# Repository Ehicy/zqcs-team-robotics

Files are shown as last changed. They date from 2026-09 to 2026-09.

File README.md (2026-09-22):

# CRTC2026 双车机器人项目

上层车推送黄块，下层车使用翻转臂和夹爪收集、接料。项目背景与当前决策见 [PROJECT.md](PROJECT.md)。

## 最新机械设计

### 翻转臂与料仓 v3（2026-09-21）

根据实物舵机照片补充MG995、SG90外形和安装托架，提供夹取、抬升、投料三个姿态。

- [完整CAD文件包](output/mechanics/flip-arm-sw-v3/FlipArm_V3_photo_fit.zip)
- [投料姿态STEP](output/mechanics/flip-arm-sw-v3/FlipArm_V3_deposit.STEP)
- [SolidWorks装配](output/mechanics/flip-arm-sw-v3/FlipArm_V3_deposit.SLDASM)
- [尺寸、照片依据和修改说明](output/mechanics/flip-arm-sw-v3/README.md)
- [舵机实物参考照片](pic/)

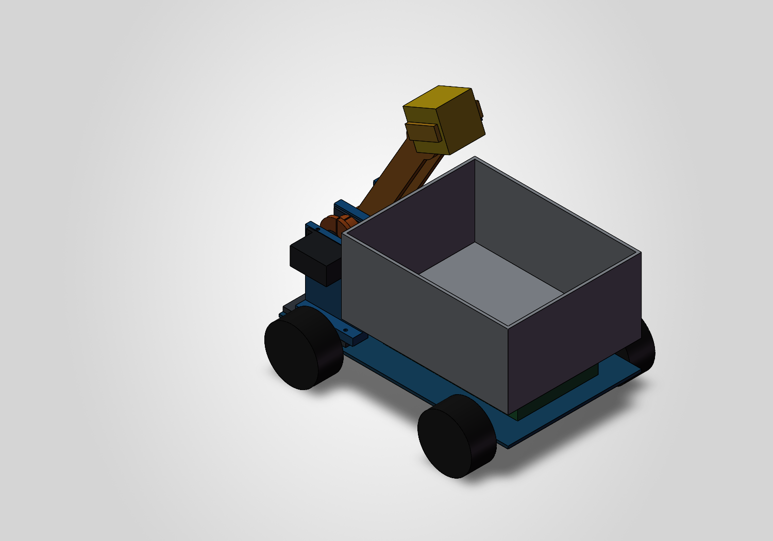
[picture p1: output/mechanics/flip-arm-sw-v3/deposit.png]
v3装配预览


原生文件使用SolidWorks 2026；下载ZIP并完整解压后打开SLDASM，保留同目录零件依赖。其他CAD软件可尝试STEP。当前为装配草案，SG90至夹指的传动、托架至腕部的连接尚未完成，不能把参考舵机和轴承模型作为打印零件。

### 桥梁试验模型

- [带两端高台的完整文件包](output/mechanics/bridge-platforms-v2/Bridge_with_platforms_TEST.zip)
- [带高台STEP](output/mechanics/bridge-platforms-v2/Bridge_with_platforms_TEST.STEP)
- [桥梁模型说明](output/mechanics/bridge-platforms-v2/README.md)
- [单段桥板模型与说明](output/mechanics/bridge-test-v1/README.md)

模型用于150mm桥面通行试验；桥曲线、厚度及净空解释包含假设，不能视为官方场地精确复刻。

## 文件位置

| 目录/文件 | 内容 |
|---|---|
| `output/mechanics/flip-arm-sw-v3/` | 当前舵机照片适配版本 |
| `output/mechanics/flip-arm-sw-v1/`、`flip-arm-sw-v2/` | 历史机械臂版本与生成脚本 |
| `output/mechanics/bridge-platforms-v2/` | 带高台的桥梁装配 |
| `output/power/`、`output/signals/` | 供电与信号方案 |
| `pic/` | 实物尺寸参考照片 |
| `PROJECT.md` | 项目背景、设计决策、工作流程和验收边界 |

CAD目录中的`build.ps1`、`build.cs`为本机SolidWorks API生成脚本；模板和API路径按本机安装配置。重新生成会覆盖相应输出，应先备份并阅读该目录说明。`backups/`、`tmp/`以及BMP预览中间文件作为本地工作资料，新文件不纳入Git。

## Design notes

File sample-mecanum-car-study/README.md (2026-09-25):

# 麦克纳姆轮小车：电控新手学习修订版

基于 Serialist/sample-mecanum-car 的 `1fa85bbdcd6c62f33f871284b642959cea975805`，2026-09-15 检查和修改。

**2026-09-24：已适配两块 DRV8833 控制四个电机，TIM2/TIM3 双输入 PWM，默认 20 kHz。实际轮位、方向、电流和遥控失联行为仍需实测。**

先打开：
- [检查与修改记录](docs/REVIEW.zh-CN.md)：发现的问题、修复方式、测试范围与剩余限制。
- [电控 B 阅读指引](docs/LEARNING.zh-CN.md)：按四个源码文件逐步学习。
- [测试结果](docs/TEST_RESULTS.txt)。
- Keil 工程：`user/rmcic.uvprojx`，保留标准库与 ARM Compiler 5 配置。

本版主循环在上电/通信异常后等待摇杆回中且按键全部松开，随后才接受控制；无效包清零电机输出。接收器若持续返回格式正确的旧帧，程序仍不能确认无线失联，须实测。

电机驱动 TODO 已完成；`TODO_GRIPPER` 仍是夹爪动作占位。当前接线、编译烧录与验收见 [DRV8833 说明](docs/DRV8833.zh-CN.md)。主机测试运行 `python tests/run_tests.py`，需要 Python 3 和 GCC；Windows 缺少 UBSan 时先设置 `$env:SANITIZE='0'`。

新增独立 GNU 构建入口：`python build_firmware.py --toolchain <Arm GNU bin目录>`，输出 `build/crtc-motor.hex`。原 Keil 工程保留。

以下保留原项目说明，材料清单和引脚描述属于上游硬件：

---

# STM32的简单麦克纳姆轮小车

## 简介

这个是一个由 STM32 最小单片机实现的简单麦克纳姆轮小车，包括了简单的 PWM 波输出和麦轮解算操作。

### 材料

- STM32F103C8T6 单片机最小系统板
- L298N 电机驱动模块
- LM2596 降压模块
- GBJ37-520 电机
- PS2 手柄及其接收器
- 小车底盘
- Keil 5

## 目录

```
├── hardware/           # 代码目录
│   ├── Inc/            # 头文件
│   └── Src/            # 程序文件
│       ├── main.c      # 主程序
│       ├── motor.c     # 底盘控制
│       ├── ps2.c       # PS2 数据接受程序
│       ├── pwm.c       # PWM
│       ├── delay.c     # 软件延时函数
│       └── sys.c       # 系统配置相关
├── lib/                # 硬件库
├── user/               # Keil 5 工程文件
└── README.md           # 项目说明文件
```

##  引脚定义

使用了PORTA PORTB

- motor PWM引脚定义

1 -> PA6  
2 -> PA7  
3 -> PB0  
4 -> PB1  

- motor逻辑引脚定义

1 -> PA8 PA9  
2 -> PA10 PA11  
3 -> PA5 PA4  
4 -> PA3 PA2  

- ps2数据引脚定义

DATA -> PB12  
CMD -> PB13  
CS -> PB14  
CLK -> PB15

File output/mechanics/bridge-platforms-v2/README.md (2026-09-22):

# 带两端高台的桥梁试验装配 v2

用户要求在原试验桥上增加高台。原v1文件保留。本装配由两座300×300×300mm高台、两段300×150mm试验桥板组成；整体长1200mm、宽300mm、最高315mm。

桥板两端上表面与高台上表面均为Y=300mm，单段中部315mm。桥板沿用v1圆弧起拱15mm、竖直厚度10mm的假设，整体上移175mm。两段相接处无高度落差，但曲线切线不连续；这种两段起拱形状没有得到官方CAD确认。

规则第15页明确高台单模块300×300mm、高300mm，并说明b4/c4两桥段相连。本模型的接收端只画一个高台模块，不包含中央四模块高台、坡道或其他场地设施。

**这是通行试验装配，不是官方桥梁的精确复刻。上移后桥下空间不满足此前按拱顶解释的130mm净高，不能用于下层车、料仓的桥下净空验算。** 本版以桥面与300mm高台无台阶连接为优先；官方截面、130mm净高含义和整桥曲线仍待核实。

## 使用

- `Bridge_with_platforms_TEST.SLDASM`：SolidWorks 2026装配，4个固定组件。必须与两个SLDPRT依赖文件放在同一目录。
- `Bridge_with_platforms_TEST.STEP`：单文件完整几何，便于其他CAD软件打开。
- `Platform_300x300x300.SLDPRT`和`.STEP`：高台单件；它是实心占位几何，不是建议实心打印的加工设计。
- `Bridge_segment_for_platforms.SLDPRT`：桥板依赖文件，装配位置由组件变换确定。
- `preview.png`：SolidWorks实际视图。
- `verification.txt`：生成校验记录，4组件，导出无错误。
- `build.ps1` / `build.cs`：可重建模型的源码，使用Windows PowerShell和本机SolidWorks 2026。重建会覆盖输出文件，应先备份；依赖上一级bridge-test-v1目录中的桥板源件。

实物试验还需设计桥段连接与支承，CAD中端面相接不代表已具备承载连接。为避免大量打印，高台实物可用尺寸合适的刚性箱体制作；第一轮可先降低离地高度试跑，但保持150mm桥宽和入口过渡尺寸。模型没有验证结构强度或行驶稳定性。

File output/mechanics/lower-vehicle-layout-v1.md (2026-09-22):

# 下方车底盘布局 v1

状态：基于用户提供的底盘照片和 **255.8×149mm** 实测外廓提出的首版空间安排；用于确定各模块大致区域和布线方向，不是底盘孔位加工图。日期：2026-09-17。

## 1. 结论

采用“**底板层布置机械与电控，上层布置收集仓和接料网**”的分层布局；底板层仍遵循“车头机械、中央电源、车尾控制”：

- 照片左端定义为车头，给翻转臂臂根和夹爪通道留出连续空间。
- 两节18650电池盒低置于底盘中央，长边沿车长方向布置。
- 两块DRV8833分别靠近左右两侧马达，减少四根马达线在控制区穿行。
- STM32和PS2接收器/转接板放在车尾，接口朝外，便于下载、插拔和观察状态。
- 三面收集网按用户草图改为收集仓上方的倒梯形导入网：上口扩大接料范围，下口对准收集仓/料槽，前侧保留翻转臂和导料通道。网架不再沿底盘边缘围一圈。

这套布局给电控留有余量，但降压模块、PS2组件和底盘孔距尚未实测，所有安装板先使用长孔或独立转接板，不直接按估算孔位打印最终件。

## 2. 坐标与建议区域

俯视底盘，车头在左。原点位于车头左上角，`x`沿车长向车尾增加，`y`沿车宽向下增加，单位均为mm。

| 部件或区域 | 建议范围 `x × y` | 预留包络 | 安排理由 |
|---|---|---:|---|
| 翻转臂臂根与运动通道 | `x=8–78, y=27–122` | 70×95 | 位于车头中央，避开四个马达区；臂根转轴初始候选在约`x=50–60`处 |
| 两节18650电池盒 | `x=87–167, y=54–96` | 80×42 | 最重部件低置于底盘中心，降低抬臂和接块时的俯仰与侧倾 |
| 5V/5A马达降压区 | `x=91–141, y=16–47` | 50×31 | 靠近电池和上侧DRV8833；实际模块未定，按保守包络预留 |
| 5V/3A舵机/控制降压区 | `x=91–141, y=102–133` | 50×31 | 靠近电池并与马达降压分开；实际模块未定 |
| DRV8833-A | `x=149–171, y=18–38` | 22×20 | 靠近上侧两只TT马达，控制这两个独立通道 |
| DRV8833-B | `x=149–171, y=111–131` | 22×20 | 靠近下侧两只TT马达，控制这两个独立通道 |
| STM32核心板 | `x=181–241, y=17–47` | 60×30 | 预留53×23mm板体、排针和USB/SWD插拔空间；接口朝车尾 |
| 主保险、开关与分电 | `x=187–245, y=54–75` | 58×21 | 靠近电池输出且能从车尾操作；正式无线断电继电器仍需另核空间 |
| PS2接收器＋转接板 | `x=181–246, y=82–124` | 65×42 | 放在车尾边缘，便于插拔和观察，远离马达及大电流线 |
| 上层收集仓＋倒梯形网投影 | 暂覆盖底板中后部上方，最终随仓容确定 | 与底板层错层 | 收集仓位于电控上方，倒梯形三面网位于仓口上方；建议用四立柱和两条横梁承力，不让网架重量压在薄仓壁或PCB上 |

以上包络含安装和接线余量，不表示模块本体就是该尺寸。现有资料中STM32核心板约53×23mm、DRV8833常见红板约18.5×16mm、双节并排18650盒常见约75–80×40–42mm。PS2按现有接收器和转接板整体预留65×42mm，收到实物后再修订。

## 3. 马达与机械安排

- 四个TT马达使用底盘四片折弯耳板安装，马达本体位于底板下方或侧下方，不占用图中的顶面电控区域。
- DRV8833-A控制俯视图上侧的前、后马达；DRV8833-B控制下侧的前、后马达。固件中仍将四个马达作为四个独立通道，不把同侧两个马达并联。
- 翻转臂支座不要只锁一个底盘孔。首版采用横跨至少四个现有小圆孔的转接底座；转轴由双侧支承承担载荷，MG995通过舵盘或连杆驱动，不让舵机输出轴单独承受整个臂的弯矩。
- 翻转臂、夹爪和方块的顶视运动通道保持在底盘中轴附近。臂根、夹爪运动包络与倒梯形网的前侧开口之间至少先留10mm设计间隙，再用完整运动模型复核。

## 4. 安装与布线

- 电池盒直接贴近金属底板固定，使用绑带和防滑垫；不要让电池只靠双面胶承受碰撞。
- STM32、PS2转接板和DRV8833使用尼龙支柱或绝缘转接板抬高约5–8mm，防止焊点和金属底盘短路。
- 5V/5A到两块DRV8833的动力线沿底盘一侧走；STM32到DRV8833的控制线沿中央或另一侧走。需要交叉时尽量接近直角。
- 四组马达线分别成对绞合并贴边固定。MG995和SG90的5V/GND直接回到舵机/控制降压分配点，不经过STM32排针。
- STM32的USB/SWD端、PS2插拔端、主开关和保险丝都朝车尾或外侧。上层收集仓采用可拆或可翻起结构，不能永久封住这些维护位置。
- 倒梯形网建议由四根立柱支撑，立柱下端连接两条横向转接梁，转接梁再用底板现有M3孔固定。收集仓独立放在立柱之间并设刚性仓底或缓冲层，不能让落块直接冲击电池和PCB。

## 5. 冻结CAD前只需补测的内容

不需要把底盘全部孔位量完。准备做安装转接件时，只补下面四项：

1. 实际5V/5A、5V/3A降压模块的长宽高和接线端方向。
2. PS2接收器插入转接板后的整体长宽高。
3. 每块转接底座最终选中的四个底盘孔：孔径及相对同一基准边的孔中心坐标。
4. 收集仓实际外廓，以及网架下口能否完整落在仓口内；网架上口和高度先做可调样架，不要求现在测比赛场地。

## 6. 资料边界

- 底盘255.8×149mm来自用户实测，照片显示为一体折弯四马达底盘。
- STM32、DRV8833和舵机外形沿用项目《器材参数.docx》及现有项目记录；商品批次仍可能变化。
- 双节18650并排电池盒常见尺寸参考：[75×40×18mm型号](https://shop.cpu.com.tw/product/41905/info/)及[77.9×40.11×21.41mm型号](https://www.dfrobot.com.cn/goods-1618.html)。
- DRV8833小板常见18.5×16mm参考：[双H桥模块商品信息](https://bearingscanada.com/products/dual-h-bridge-motor-driver-module-drv8833-for-dc-m)。
- PS2转接板的图片、稳压和反接保护特征来自用户提供的器材资料；未取得该批次尺寸图，因此采用空间预留而非制造尺寸。

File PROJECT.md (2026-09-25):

# CRTC2026 小车项目

本文件是本项目的长期记忆，记录当前目标、已采用方案、依据、待验证事项与继续工作的入口。团队已确认参加**新生组**，采用**上层车推送、下层车收集**的分工；先验证基础行驶与关键机械路径，再分别完善两辆车。

**当前阶段：结构、供电与信号接线设计。尚无已验证的整车或正式加工图；已有固件源码与构建入口。** “最终电源图”表示本轮讨论选定的连接方案，不表示已经通过实物测试；信号图为建议引脚分配。

后续工作先读本文件。用户的新指示优先；比赛约束以本地规则原文及后续官方修订为准。旧设计文档与本文件冲突时，使用本文件中的当前方案，不把历史建议恢复成要求。

## 1. 背景、目标与设计原则

- 比赛最终使用两辆车；团队成员是新手，优先结构简单、少采购、容易接线和调试。
- **上层车：**类似推土机，取消夹取与存取功能，目标是将挂架及中央黄块推落；先验证原底盘过150mm桥面的能力，再决定是否缩窄轮距，具体推板、拨片与轮组尺寸待定。
- **下层车：**保留 **MG995 翻转臂＋SG90 夹爪**的收集功能，由操作手操控接收上层掉落的黄块；接料口计划在收集仓上方安装**三面倒梯形收集网**，以较大的上口扩大接料范围并把方块导入仓口，具体尺寸待样块验证。
- 两车底盘沿用四个 TT 马达、两块 DRV8833、STM32 核心板与 PS2 手柄控制的基础方向。可复用电控与行驶验证结果，不再默认整车机械结构相同或直接复制。
- 首个上电 Demo 先打通供电与遥控行驶；同时提前验证挂架脱杆、台阶遮挡和下层接料路径。下层再验证翻臂、夹取与入槽；精确堆满 8 块不是首个 Demo 的前置条件。
- 电池尽量低置，臂根有独立承力支承；用实际负载验证稳定性，不能只凭三维外观判断可行。
- 电流规格分清“实际耗电”“堵转预算”和“电源输出能力”。不得把额外余量反复叠加成最小 Demo 的硬性采购门槛，也不得把模块商品标题当作已验证能力。

## 2. 文件与工程现状

| 路径 | 用途与状态 |
|---|---|
| [CRTC2026规则文档v1.0.pdf](CRTC2026规则文档v1.0.pdf) | 比赛约束原文；封面版本与正文版本标记有差异，引用时以具体条款为准 |
| [器材参数.docx](器材参数.docx) | 官方清单器材、参数与参考外形；清单数量不等同于已到货、已测量数量 |
| [PROJECT.md](PROJECT.md) | 当前项目记忆与决策入口 |
| [最终电源连接图](output/power/robot-demo-power-final-v1.png) | 保留翻臂与夹爪的下层车两路供电基线；上层车负载改变后须单独核对，图尚未更新 |
| [信号接线图（简洁版）](output/signals/robot-demo-signal-wiring-simple-v1.png) | 下层车接线建议；上层可复用行驶与PS2部分，舵机接口按实际机构确定；GPIO不是实物排针位置图 |
| [方块质量、导料与夹取核算](output/mechanics/block-gripping-study-v1.md) | 依据规则第13–17页的几何核算、摩擦敏感性计算、洞口与挂架取块限制；未经过实物验证 |
| [下方车底盘布局 v1](output/mechanics/lower-vehicle-layout-v1.md) | 基于255.8×149mm实物底盘的模块分区、翻转臂预留和布线方向；孔位及降压模块尺寸待实测 |
| [桥面通行试验CAD v1](output/mechanics/bridge-test-v1/README.md) | SolidWorks/STEP/STL，单段300×150mm，圆弧起拱15mm；10mm板厚及净高解释为试验假设，不是官方完整桥梁复刻 |
| [带高台试验装配 v2](output/mechanics/bridge-platforms-v2/README.md) | 两座300×300×300mm高台＋两段300×150mm试验桥，桥端升到300mm与台面齐平；SLDASM/STEP。沿用试验圆弧，不能用于官方130mm桥下净空验算，原v1保留 |
| [翻转臂与料仓CAD v2](output/mechanics/flip-arm-sw-v2/README.md) | SolidWorks零件及夹取/抬升/投料三姿态装配、STEP；夹爪为占位，安装接口及收拢姿态未定，不是整套加工完成件 |
| [舵机照片适配CAD v3](output/mechanics/flip-arm-sw-v3/README.md) | 根据pic实物尺照补MG995与SG90外形、SG90托架，修正MG995朝向及支架/底座对应孔；保留v2料仓与臂长，夹爪传动和腕部连接未完成 |
| [小车结构与接线方案.md](小车结构与接线方案.md) | **历史详细草案**；其三路供电、主动分料、9 块容量、4.8V 舵机电源及部分采购要求已被后续讨论替代。尺寸、引脚表仍仅供参考 |
| `tmp/sources/` | 文档提取、参考图片及早期三维演示检查材料；不是固件代码目录，不作为长期事实来源 |
| `backups/` | 旧文档备份，用于追溯，不代表当前设计 |

电控源码位于 `sample-mecanum-car-study/`。2026-09-24 已完成 DRV8833 电机驱动；保留 Keil/ARM Compiler 5 工程，新增 Arm GNU 构建入口，无 CubeMX 工程。详见 `sample-mecanum-car-study/docs/DRV8833.zh-CN.md`。不得把 `tmp` 中的可视化脚本当成机器人控制程序。

## 3. 必须保留的比赛边界

以下依据本地规则及前期读取结果；正式参赛前复核原文与最新答疑。

| 项目 | 约束及对设计的影响 |
|---|---|
| 初始尺寸 | 长宽高不超过 **260×190×200mm** |
| 展开尺寸 | 当前按规则允许的长宽高包络 **435×400×450mm** 路径检查，需包含机构运动范围 |
| 重量 | 上限 **2.0kg**；装载道具如何计入检录重量仍须核对官方解释 |
| 电池 | 使用 **18650**；每车一个供电模块，额定电压不超过 **7.4V**，电池组一个对外输出接口；接口之后再分两路降压 |
| 断电 | 正式比赛必须适配官方无线继电器，可遥控切断底盘电源。当前 Demo 图未画该组件，不能据此认为比赛可省略；型号和端子接法待确认 |
| 成本 | 新生组全队机器人总成本上限 **420 元**；无线继电器采购按规则例外处理。未完成当前方案的实际报价核算 |
| 桥与轮组 | 桥面约 **150mm** 宽，整车限宽 **190mm** 不等于轮子能获得桥面支撑。轮子外宽、实际接触位置与桥侧干涉都需验证 |
| 方块与携带 | 方块外形约 **40mm**，中心镂空约 **20mm**。携带要求道具随车运动；规则未明确要求封闭料仓或整车倒置后仍不掉块 |
| 对抗与强度 | 低速挤压与破坏性冲撞须区分；主动铲翻并未确认合规。正式检录包含底面朝下的跌落检查，具体按规则执行 |

料仓默认可采用**有底、带挡边的敞口结构**。不得把上盖、单向门、倒置保块当作本项目首版的强制要求。

## 4. 当前采用的电源方案

### 4.1 下层车器件与连接、上层车适用范围

下层车使用：4 个 TT 马达、2 块 DRV8833、1 个 MG995、1 个 SG90、1 块 STM32F103C8T6 核心板、1 套 PS2 接收器/转接板、1 组两节串联的 18650 电池。

本节两路供电图及两舵机电流预算作为**下层车基线**保留。上层车取消夹取与存取机构，不再默认配置这两只舵机；是否需要驱动可收起拨片的舵机尚未确定。上层保留马达与控制供电需求，待机构确定后重新核算B支路负载、模块与采购数量，不能直接照搬下层两舵机预算，也不能因取消舵机而取消主控供电。

用户已确认所查舵机工作电压为 **4.8–6V**，因此当前统一使用固定 **5V** 供电，不再要求舵机支路必须调到 4.8V。

| 支路 | 当前新增模块 | 负载 |
|---|---|---|
| A：马达 | **固定 5V、持续 5A** 降压模块 ×1 | 两块 DRV8833 的 VM，四个 TT 分别由四个独立 H 桥通道控制 |
| B：舵机与控制 | **固定 5V、持续 3A** 降压模块 ×1 | MG995、SG90、STM32 核心板 5V 入口、PS2 转接板 5V 输入；从模块输出处分支接线 |
| 备用 | 原有小 5V 降压模块 | 暂不接入；若共用 B 支路导致控制系统复位或掉线，再单独供控制系统 |

```text
两节 18650 串联：标称 7.4V，满电 8.4V
  正极 → 近电池保险丝 → 主开关 → 分电
                                 ├ A：5V / 5A
                                 │   ├ DRV8833① → 通道A接马达1、通道B接马达2
                                 │   └ DRV8833② → 通道A接马达3、通道B接马达4
                                 └ B：5V / 3A
                                     ├ MG995
                                     ├ SG90
                                     ├ STM32核心板5V入口 → 板载稳压 → 3.3V → 主控芯片
                                     └ PS2转接板5V输入
  负极 → 公共GND → 降压模块、驱动板、舵机、核心板、PS2转接板的GND
```

- 两个降压模块的**输入**接同一电池分电点；两个模块的**输出正极不得并联**。
- 电机的两根线接它所属 H 桥通道的两个输出端，不直接接降压模块，也不把其中一根线固定接公共地。
- 舵机和控制系统从 B 的输出端分别布线。舵机电流不经过 STM32 板、PS2 板或面包板；供电线与回流线要可靠。
- STM32 **核心板**上的额外稳压器负责 5V 转 3.3V，不能把“STM32 芯片本身”当成能直接接 5V。5V 不接 3V3/VDD 引脚。
- 器材资料写明核心板可从 5V/USB 供电，PS2 转接板有稳压功能；实际端子和板型仍须核对，不能凭示意图中的器件外观接针脚。
- 供电图描述电源与马达输出；舵机 PWM、DRV8833 输入和 PS2 通信线见信号图及4.4节。GPIO仍是建议分配，尚未通过实物和固件验证。

### 4.2 电流依据与适用范围

| 数值 | 来源与使用方式 |
|---|---|
| MG995 堵转电流 **1800mA** | 用户查得；尚未提供原始链接或实测记录，具体测试电压待核对 |
| SG90 堵转电流 **860mA** | 用户查得；同上 |
| 两舵机合计 **2.66A** | 1.80＋0.86，是采用上述数据的同时堵转预算，不是正常运行电流 |
| 控制系统预留 **0.15–0.30A** | 设计估算，未测量 |
| B 支路合计约 **2.81–2.96A** | 条件性预算：上述舵机数据适用于本机 5V 供电时才可直接使用。接近 3A，作为 Demo 试验方案，需验证动态电压与温升 |

堵转电流可用于相同电压下的最大稳态负载预算；不应把同一启动需求再重复相加。它不保证覆盖所有瞬态，也不表示器件可以长期堵转。此前 MG995 2.5A、SG90 0.8A 的估算不再作为当前预算依据。

四个 TT 的当前 5A 支路用于轻载、缓起步 Demo。前期同类 1:48 TT 参考样品在 6V 下空载约 0.16A、堵转约 1.5A；不是本批次在 5V 下的实测参数，不能直接断言比赛爬坡与顶推均足够。

DRV8833电流要按**每个H桥通道**与整板散热分别核对。TI在VM=5V、25℃条件下列出PWP/RTY封装每桥1.5A RMS、2A峰值，PW封装每桥0.5A RMS、2A峰值；这些不是任意红板双通道同时工作的保证值。本车具体封装、PCB散热、限流配置和TT实际电流仍未确认。截图所称“单板统一只有1.2A，两板共2.4A”没有对应板型依据，不采用为统一规格。5V/5A是电源供电能力，不强迫驱动板消耗5A，也不保护某个通道免于过载；四个电机分别走四个通道，不能把总电流当成流过单个通道。DRV8833有过流和过温保护，但不能据此允许长期堵转；也不能把正常启动或一次堵转直接判为必然烧毁。当前保留两板带四马达的轻载Demo方案，持续顶推能力须单独验证。

### 4.3 采购与验证原则

- 下层车沿用新增 **1 块 5V/5A＋1 块 5V/3A** 的验证方案；上层车按最终执行机构另核B支路，不再默认两车采购完全相同。采购、到货和模块具体型号均未确认。
- 要求模块在电池满电 8.4V，以及放电后约 6–6.4V 的测试条件下仍能稳定输出 5V。此处是验证区间，不是已确定的电池截止电压。
- “3A/5A”应对应模块实际持续输出条件；芯片最大开关电流、商品峰值与整板持续电流不是同一指标。
- **XL4015 官方输入下限为 8V**，不作为当前两串电池方案的默认选型；增加同款板数量不能解决输入电压不匹配。
- B 支路出现控制复位/遥控掉线时，先定位供电与接线问题，必要时启用原有小降压板单独供控制系统。A 支路实测能力不足时，才考虑拆成每块带两个马达。
- 用户选择先做Demo，再按实测决定是否额外增加滤波／储能电容；不把新增大电解电容一律列为首轮采购前提。上电前仍应核对成品驱动板已有芯片需要的外围元件：TI建议DRV8833的VM就近以至少10μF陶瓷电容接GND，VINT/VCP另有各自配套电容。系统供电图未画出这些元件不表示板上没有；缺失基本外围元件不能等出问题再补，额外储能电容是否足够也不能仅凭外观判断。
- 干扰判断区分欠压与过压：单纯短时欠压通常导致复位或通信异常，不代表烧毁；超过器件额定限制的尖峰可能造成永久损坏，不能把“最多只是STM32掉电”作为验证前提。保持共地并分别布置大电流回路，先轻载缓启停测试；出现复位、抖动或异常发热先停下定位，电压尖峰需示波器等适当测量方法确认。尚无本车瞬态测量结果。
- 电池、保护、主线或 DRV8833 限流/散热不足，不能靠增加降压模块修复。当前图不代表这些器件已验收。

### 4.4 信号接线建议

下层车采用[简洁版信号图](output/signals/robot-demo-signal-wiring-simple-v1.png)。上层车可复用马达与PS2信号分配，PB6/PB7不再默认接翻臂与夹爪，是否用于拨片执行机构待定。用户偏好简单、少装饰的接线图。图内各分区均连接**同一块 STM32F103C8T6 核心板**；引脚名称不表示排针物理顺序。以下分配利用芯片默认定时器映射，不启用对应定时器的引脚重映射；未确认实际核心板是否全部引出这些引脚。

| STM32引脚 | 连接端 | 信号方向／建议功能 |
|---|---|---|
| PA0 | DRV8833① AIN1 | 输出，TIM2_CH1 |
| PA1 | DRV8833① AIN2 | 输出，TIM2_CH2 |
| PA2 | DRV8833① BIN1 | 输出，TIM2_CH3 |
| PA3 | DRV8833① BIN2 | 输出，TIM2_CH4 |
| PA6 | DRV8833② AIN1 | 输出，TIM3_CH1 |
| PA7 | DRV8833② AIN2 | 输出，TIM3_CH2 |
| PB0 | DRV8833② BIN1 | 输出，TIM3_CH3 |
| PB1 | DRV8833② BIN2 | 输出，TIM3_CH4 |
| PB6 | MG995 的 S | 输出，TIM4_CH1，翻转臂 PWM |
| PB7 | SG90 的 S | 输出，TIM4_CH2，夹爪 PWM |
| PB14 | PS2 DI/DAT，接收器① | **输入**，接收器 → STM32 |
| PB15 | PS2 DO/CMD，接收器② | 输出，STM32 → 接收器 |
| PB12 | PS2 CS/SEL（也称ATT），接收器⑥ | 输出，低电平选中 |
| PB13 | PS2 CLK，接收器⑦ | 输出，由STM32提供时钟 |

- **驱动板：**①的A/B通道分别接马达1/2，②分别接马达3/4。GPIO接AIN/BIN输入，马达接各自AOUT/BOUT输出。3.3V逻辑满足DRV8833输入高电平门限；不能由此推断所有外围模块都支持相同电平。
- **nSLEEP：**运行时必须为高电平；芯片本身有下拉，不能默认悬空也能运行。先查实际驱动小板是否已上拉或固定接高；若需外控且不存在板载固定电平冲突，可预留PA8控制两板。未确认板型前不将该可选线画成必接线。
- **舵机接口：**按用户照片，G是黑色或棕色、V是红色、S是白色或橙色。两种线色不强行对应到具体舵机型号。V接B路5V，G接公共地，S分别接PB6/PB7；舵机供电电流不经过核心板。PWM可从50Hz开始，脉宽和行程按实际机构校准；3.3V控制信号是否被本批舵机可靠识别需实测。
- **PS2接口：**按用户照片的接收器正面朝向编号，④为GND、⑤为VDD，③⑧⑨未使用。9针插座编号不能直接当成6针转接板排针顺序，应按转接板丝印对应DAT/CMD/SEL/CLK/GND/电源入口。
- **PS2电源：**用户照片写接收器VDD允许3–5V；《器材参数.docx》中的转接板资料另写有板载3.3V稳压。当前按B路5V接该转接板电源入口，再由其稳压供接收器⑤VDD 3.3V绘图；不把接收器⑤误标为转接板5V入口。实际板型不同应重新核对。资料所称保护电阻不等同于已证明具有电平转换，DAT实际电平及上拉配置仍需确认。
- **固件预留：**PA13/SWDIO、PA14/SWCLK留给下载调试；没有第三只分料舵机。PS2先可用GPIO模拟通信，确认协议时序后再决定是否用硬件SPI；马达PWM使用TIM2/TIM3，舵机PWM使用TIM4，避免将马达频率和舵机帧频混用。
- **接线验收：**所有模块共地；下层逐根核对14根主信号线及驱动使能状态，上层按实际安装机构核对，再分别测试马达、已安装舵机和手柄。图纸核对完成不等于已完成上电验证。

### 4.5 车内接线与模块底板（建议，未定案）

用户指出车内空间有限，散线整理及公共地连接困难。当前建议桌面单模块调试仍可手工连接，装车优先考虑简单的双层模块底板PCB：保留现成STM32核心板、两块DRV8833、降压模块和PS2转接板，用插座、端子及PCB走线集中连接；不是重新设计各裸芯片电路。用户尚未确认开始正式PCB设计。

共地表示各GND电气连通，不要求所有地线焊到同一个物理点。底板应提供连续、低阻的地连接，并按布局安排马达和舵机的大电流回路，避免经过核心板的细地线；A路5V与B路5V输出正极仍须分开。模块电源触点、铜线、过孔及端子都需按实际电流选型，不能认为铺铜后自然满足5A。

下层底板可集中两只舵机G/V/S接口、四个马达双线接口、PS2接口和SWD接口，并预留可选电容焊盘；上层接口按实际机构配置，是否共用底板待定。降压模块是否装在同板、板框大小和插座位置，须取得实际模块尺寸、引脚顺序、安装高度以及各车底盘可用空间后确定；目前没有可制造PCB文件。

## 5. 机械方案的当前状态

**2026-09-21舵机实物依据：**`pic/`中8张尺照确认TIANKONGRC MG995与SG90。MG995主体沿用40.5×20mm，含耳长按约54.5mm；SG90主体按约23×12mm、含耳长约32mm拟合。照片有视差，壳高、凸台、耳位和孔距的具体建模值见v3说明，不记为精密实测。v3保留现有仓容与高度，补两只舵机外形及安装接口；未据照片确认舵盘花键/孔位，也未完成SG90至夹指的传动。

**2026-09-18当前建模基线：**下层单车目标容量12–16块，料仓与149mm底盘同宽，后部及侧部接料；停车d3时车头朝a3。收集网为后装二号方案，当前建模不含网。用户确认车轮外径60mm，要求仓下保留面包板及一层元器件空间，不因层层叠加估算余量推翻原布局。v2暂用底盘上表面离地35mm、电控高25mm、仓底内面离地68mm、内仓180×143×80mm（仓沿148mm）；这些高度为可调整建模值，不是实测。臂轴离地110mm、臂板孔距130mm、名义夹持半径150mm；提供三种工作姿态。旧v1及下述早期布局仅作参考，仓底25–30mm不再采用。待实际接口确定后细化，未验证初始收拢包络和满仓桥下通过。

**2026-09-17 用户确认的分工：** 上层车改为推土机式推送车，不保留夹取和存取功能，目标是推落挂架与中央黄块，轮距较窄；下层车保留翻转臂＋夹爪收集功能，并由操作手操控接收掉落黄块。原两车统一夹取与储存的方向被替代；原三维模型不能作为当前加工依据。

**用户补充的接料方向：**下层三面收集网位于收集仓/料槽正上方，外形为上大下小的倒梯形导入网，上口扩大接料范围、下口对准仓口；不是沿底盘边缘设置的围网。三面的具体朝向、网材、网孔、张紧程度、支架尺寸及是否折叠尚未确定；不得将其记作已完成或已验证的机构。

**下方车底盘首版布局：**以用户实测255.8×149mm底盘为准，底板层采用“车头机械、中央电源、车尾控制”的分区。照片左端暂定义为车头，前部预留约70×95mm翻转臂臂根及运动通道；双节18650盒低置中央；两块DRV8833靠左右两侧马达；STM32和PS2放车尾并让插拔端朝外。收集仓和倒梯形三面网位于底板中后部上方，与电控形成上下层；建议四立柱通过两条转接梁锁到底板原孔，收集仓可拆，不让网架或落块直接压到PCB。具体坐标、安装与布线见[下方车底盘布局 v1](output/mechanics/lower-vehicle-layout-v1.md)。这不是已冻结CAD，降压模块、PS2整体、收集仓外廓和所用底盘孔仍待最小实测。

**建议的实现与操作方式，尚未定案或实测：**

- 上层中央块使用低位推板缓慢推向选定边缘；挂架块须沿杆推向自由端并完全脱杆，不能直接下压。研究固定推板配下探拨片/推叉，比较固定拨片与可收起拨片的通过性，再决定是否保留一只执行舵机。
- 协作优先试验“下层先对位停车 → 上层缓慢推落 → 确认接住再继续”。不把方块开始下落后追车接住作为可靠性前提。
- 下层围绕仓口上方的倒梯形三面网（机械臂一侧无网避免阻挡）研究接料结构：较大的上口拦截偏差，下口必须完整落在有底收集仓的入口内，不能让方块滞留在网兜、卡在网仓接缝或从前侧开口漏出。适度缓冲减少反弹，网面倾角与张紧程度通过样块试验确定；接料时翻臂避开网架与入口，夹爪负责地面收集及可达位置的漏接补收。
- 收集网需验证镂空方块的棱角、孔边是否挂网，以及网面下垂、边缘缝隙和连续落块是否造成滞留或漏接。网架计入初始与展开尺寸，并检查满载重心、场地碰撞、翻臂完整运动范围；三面网扩大接收容错，但不能代替对挂架下方台阶遮挡的验证。
- **挂架路径是关键待验证项：**按现有场地图，150mm长挂杆下方有向外约300mm的台阶，脱杆点可能仍在台阶上方。不能假设脱杆后直接落到地面车；须检查是否先落在台阶、下层接料口能否到达，以及是否需要引出台阶的导料结构。伸距、碰撞和展开尺寸一起核对。
- 上层窄轮距服务于桥面通行；区分接地点间距、轮外宽和整车宽。电池低置，验证边缘推块的偏心受力与侧倾，推送机构应允许车轮留在平台安全位置完成动作。

**仍未定案的部分：**

- 用户此前提出 **2×2×2 堆叠、共 8 块** 的目标；新分工下上层不设仓，下层目标容量及排列须重新确认，不把旧目标自动当作新方案验收要求。固定单轴翻转臂不能独立选择左右两列，不能承诺只靠投放角度就实现整齐 2×2×2。
- 助手提出过 **前后4×左右1×上下2** 的 8 块长槽备选，以及先验证单层4块再试第二层的顺序；用户尚未明确确认该排列，不能记作最终布局。
- 料槽倾角、挡边高度、净宽、实际容量、夹爪退出间隙及各投料角，均待样件验证。改变翻臂角度同时改变水平位置和高度，不是独立升降。
- 上层先测试原底盘过桥：用户确认轮胎外侧间距大于150mm、内侧间距小于150mm，具体数值未知。2026-09-18建立仅含中间桥板的试验CAD，验证部分胎面搭接及麦轮滚子接触稳定性后，再决定是否缩窄轮距。此前135/185mm是比较值，135–140mm不是已测尺寸或最终轮宽。下层轮距独立按接料和稳定性确定。
- 臂根约85mm、臂长约180mm、车体约250×185mm等均来自旧概念布局。简化机构后应重新检查，不能直接下单加工。
- 电池低置；分别检查空载、装块、抬臂时的重心与支撑范围。八块两层堆放对高度、重心和行驶保块的影响尚未验证。

上下层资源交接分工已确定，但推落顺序、落点、下层常态携带数量和最终仓容仍待验证。推土机式功能指推送道具，不意味着采用主动铲翻对手的机构。

### 5.1 方块、导料与取块路径的核算结论

详细公式、依据、假设和试验方法见[方块核算报告](output/mechanics/block-gripping-study-v1.md)。以下为2026-09-16核对本地规则第13–17页后的结论：

- **几何与质量：**规则图是六面开孔的立体框架，外40mm、孔约20mm，未倒角名义棱条宽10mm。用户确认PLA材质，但未给打印填充率、壁数和倒角尺寸。按全部棱条实心、无倒角、参考密度1.24g/cm³计算，体积32cm³、单块39.68g、8块317.44g。当前可用约40g/块作普通PLA的初步负载估算，不是实测值；此前30g仅为示例，不能作为已知质量。不能直接用40³−20³计算六面开孔框架，也不能直接用整块质量乘切片填充率。
- **摩擦：**导料槽材质未定。理想单底面接触时起滑要求tanθ＞μs，质量在判据中抵消。μs假设0.3/0.4/0.5/0.6时临界角约16.7°/21.8°/26.6°/31.0°；这些不是材料实测系数。先用真实样块及候选底板测倾斜起滑角，再确定角度。槽底连续平整，并验证方块孔边、接缝及多块相互卡住；倾斜槽不能自动保证2×2×2堆叠。
- **洞口取块：**规则写洞穴70×70×50mm、方块外平面齐洞口、径向居中；宽70、深70、高50mm是本次计算的轴向解释，仍应核对实物。左右薄夹指有空间：例如内开口50mm、两侧各4mm，外宽58mm。应夹实体棱、保持低位先直线退车约45–50mm，方块完全离洞后再抬臂；不假设底下有托钩间隙。进入部分包络、橡胶垫、连杆与姿态要一起验证，不能仅凭夹爪开口尺寸判定整机可行。
- **挂架取块：**杆直径14mm、长150mm、轴高250mm；图中块位于靠高台墙的杆根，下方有300×300mm、高150mm台阶。方块必须沿杆滑向自由端并完全脱杆，不能直接向上提。旧转轴高85mm、有效半径180mm在目标高度247–250mm时仅剩约72–78mm水平伸距，不能从地面直接跨过该台阶夹到杆根。必须先明确支承位置、接近路线、退杆行程及碰撞包络，不把臂加长到某距离当作已解决。
- **机构与总体布局：**旧稿曾有被动平行四边形保持夹爪姿态，下层是否保留尚未确认；刚性单臂的夹爪姿态随臂角变化，须检查洞内取块与入槽。上述旧夹爪挂架可达性结论保留作历史限制，新分工不再要求下层直接夹取挂架块。先完成上层推落、下层接收及夹取入槽的机械路径检查，再冻结各车PCB外形及连接器位置。

## 6. 工作流程、运行与验收

电控按基础 Demo 推进，固件目录为 `sample-mecanum-car-study/`：
- `hardware/Src/main.c`：PS2有效性、回中使能、按键与底盘主循环；`ps2.c`：手柄通信；`motor.c`：死区/麦轮混合；`pwm.c`：DRV8833双输入PWM。
- `motor_init()` 内部初始化TIM2/TIM3，电机输入按4.4节；20 kHz为72 MHz定时器时钟下的初始参数，停机采用0/0滑行。PS2也已按4.4节对齐；nSLEEP依赖硬件保持高，不启用PA8。
- 在该目录运行 `python tests/run_tests.py` 进行主机测试；Windows GCC缺少UBSan时先设 `$env:SANITIZE='0'`。运行 `python build_firmware.py --toolchain <Arm GNU bin目录>` 生成 `build/crtc-motor.hex`，用STM32CubeProgrammer经ST-Link/SWD下载及校验。Keil工程仍为 `user/rmcic.uvprojx`。
- 2026-09-24已用xPack Arm GNU GCC 15.2.1编译，经STM32CubeProgrammer 2.23.0/ST-Link烧录并校验、复位；独立读回5304字节一致。TIM2/TIM3运行、PSC=0/ARR=3599、八路CCR=0；采样时PS2无有效帧，电机与手柄联动尚未验收。日志见 `sample-mecanum-car-study/docs/FLASH_RESULTS.txt`。
- 主机测试不能替代PWM波形、方向、温升和遥控失联实测。尚未实现起步/反转斜坡、轮速闭环、舵机动作和独立看门狗；接收器有效旧帧问题仍未解决。

| 阶段 | 工作与验收标准 |
|---|---|
| 0. 推落与接料路径 | 复刻高台边缘、挂杆及下方台阶，用手持推片和接料口模型验证中央推落、沿杆脱出、落点与遮挡；记录接料成功和失败原因，通过后再冻结推板/拨片及接料结构 |
| 1. 实物核对 | 记录降压板型号、输入范围、持续电流条件，核对核心板与PS2输入端；确认电池、驱动板和线材实际到货情况 |
| 2. 电源台架 | 先断开负载调试/测量，再逐项接入。两路均为5V；负载动作时无反复保护、明显掉压或异常发热 |
| 3. 基础固件 | 确认开发环境和引脚；保留SWD调试。先完成PS2读取，再分别测试每个马达与舵机方向及行程。上电和遥控失联时应停止轮驱动 |
| 4. 行驶 Demo | 先架空轮子检查四通道，再轻载落地验证前进、后退和转向；缓起步，避免直接高速反转 |
| 5. 分车机构验证 | 下层先空臂、再带块验证夹取、抬升、释放与退出；上层验证推送、脱杆、退车及拨片通过性，检查推送受力和驱动温升；不长期堵转或顶机械限位 |
| 6. 电控联动验收 | 各车马达与已安装执行机构联动时，STM32不复位、PS2不掉线、舵机无异常动作；失败时定位电源/驱动/程序原因，不仅凭“电流够大”判断 |
| 7. 下层接料与存储 | 分别验证夹取入槽和三面收集网接收落块；覆盖入口中央、网面、边角及连续落块，检查挂网、滞留、反弹、缝隙漏块、翻臂与网架干涉、满载入口及行驶保块；记录停车偏差下实际导入承接区域的成功情况。容量按新布局确定，8块满仓不是首个Demo必达项 |
| 8. 双车与比赛完善 | 练习下层先对位、上层再推落的协作，验证漏接补收；分别核对两车尺寸、质量、官方遥控断电、强度和预算，上层重点验证窄轮组过桥、坡道及平台边缘稳定性 |

每次实测至少记录：供电电压、器件型号、负载/动作、输出端及负载端电压、测量方法、是否复位/掉线/过热。电流数据注明空载、典型负载或堵转条件；普通万用表平均读数不能当作捕获全部瞬态的证据。

## 7. 重要设计变更与未采用方案

| 历史方案或说法 | 当前处理 |
|---|---|
| 两车统一翻臂、夹爪和料仓，验证一辆后整车复制 | 2026-09-17改为上层推送、下层收集；上层取消夹取与存取，采用较窄轮距，下层保留翻臂＋夹爪并接收落块；基础电控可复用 |
| 三路供电，逻辑始终独立 | 当前Demo采用两路，舵机和控制合并；原小板留作故障排查/恢复独立逻辑供电的备用 |
| 舵机支路必须可调4.8V、必须5A | 用户确认舵机支持4.8–6V；改固定5V。按用户提供的堵转参数，先用真实3A模块验证 |
| 马达必须6A持续、8A峰值 | 不作为最小Demo硬门槛；当前5V/5A轻载验证，测量后再决定是否调整 |
| 每车买3块大降压板，两个马达分一路 | 曾讨论的备选；当前仍是一块供四马达，另一块供舵机和控制 |
| 回转导流斗＋第三个舵机＋三条料道，每车9块 | 因复杂度过高被简化方向替代；下层保留MG995与夹爪SG90，料仓排列未冻结；上层不设料仓，拨片是否需要舵机待定 |
| 封闭仓、单向门、倒置不掉块是必需条件 | 已撤回；默认可做有底有挡边的敞口料仓 |
| 改变车头方向能改变夹爪相对车上料仓的投放位置 | 不成立；二者随车一起运动。需改变机构相对位置或依靠导料结构 |
| 4×1×2长槽已经被用户选定 | 未确认，只是针对单轴翻臂提出的备选，不得覆盖用户最初2×2×2的讨论目标 |
| 85mm臂根＋180mm臂能升到250mm，所以能取挂杆方块 | 高度判断遗漏150mm台阶和杆根位置；撤回“已能取”的结论，先验证接近路线、沿杆退出及完整碰撞包络 |

## 8. 后续维护与核对入口

- 新采购、接线、引脚、实测和机械布局确定后，更新对应章节，清楚区分“用户提供”“资料参考”“计算估算”“实物验证”。
- 仅保留影响后续工作的决策，不把搜索过程、图像修改过程和临时尝试写成流水账。方案替代时更新正文，并在设计变更表保留简短理由。
- 固件/CAD建立后补全实际文件结构、工具版本、构建/下载步骤和验收记录入口。文档、源码完成、编译/下载成功与实车运动验收须分别记录，不能相互替代。

可复核的一手资料：

- [ST：STM32F103C8](https://www.st.com/en/microcontrollers-microprocessors/stm32f103c8)：芯片电源与接口范围；不代替具体核心板原理图。
- [ST：STM32F103x8/xB数据手册](https://www.st.com/resource/en/datasheet/stm32f103c8.pdf)：表5核对GPIO与默认定时器功能，用于4.4节建议分配。
- [TI：DRV8833](https://www.ti.com/product/DRV8833)：驱动工作范围、封装和电流能力；不代替所购小板散热与布线能力。
- [TI：DRV8833数据手册](https://www.ti.com/lit/ds/symlink/drv8833.pdf)：输入高电平门限、nSLEEP及H桥端子定义。
- [XL4015官方资料](https://www.xlsemi.com/datasheet/XL4015-CN.pdf)：输入范围从8V开始。
- [Adafruit：1:48 TT参考样品](https://www.adafruit.com/product/3777)：参考电流实测；不是本批次马达证明。
- [Pololu：电机与电源选择](https://www.pololu.com/docs/0J73/4.1)：堵转、启动与反转瞬态的区别。

用户提供的MG995 1800mA、SG90 860mA参数仍等待商品资料或实际测量补充，不能拿其他型号、不同版本舵机的参数冒充已确认值。

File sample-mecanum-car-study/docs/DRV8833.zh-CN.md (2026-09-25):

# DRV8833 电机控制（2026-09-24）

本版将旧 L298N 的方向脚＋独立 EN 改为 DRV8833 双输入控制；保留原四轮编号、麦轮混合、死区、整体限幅及启动/异常恢复回中保护。没有编码器闭环、起步/机械反转斜坡或软件限流。

## 接线与输出

| 电机 | 模块通道 | IN1 / IN2 | 定时器通道 |
|---|---|---|---|
| 1 | DRV8833① A | PA0 / PA1 | TIM2 CH1 / CH2 |
| 2 | DRV8833① B | PA2 / PA3 | TIM2 CH3 / CH4 |
| 3 | DRV8833② A | PA6 / PA7 | TIM3 CH1 / CH2 |
| 4 | DRV8833② B | PB0 / PB1 | TIM3 CH3 / CH4 |

PS2：DAT=PB14（输入）、CMD=PB15、CS=PB12、CLK=PB13，现已与根目录 PROJECT.md / 信号接线图一致。旧代码的 PS2 接法不能继续照用。TIM4 与 PB6/PB7 留给后续舵机；PA13/PA14 保留 SWD。

pwm_set1～4 的参数现在是带符号的 -1～1，超过范围限幅、NaN 归零。正向 PWM/0，反向 0/PWM，零输出与 motor_stop 均为 0/0 滑行，不是主动刹车；依据 [TI DRV8833 数据手册第9页表1/2](https://www.ti.com/lit/ds/symlink/drv8833.pdf)。每对输入先清旧方向，再给新方向；CCR 无预装载，因此清零无需等待更新事件。此写入顺序不等于电机已经减速，也不保证限制快速反转电流。

motor_init 内部初始化 GPIO 和 TIM2/TIM3；八个输入预置低，比较值清零后才切为复用 PWM。默认定时器映射。正常 HSE=8 MHz、系统72 MHz条件下，PSC=0、ARR=3599，PWM 为20 kHz。若晶振启动失败退回8 MHz，实际频率随时钟降低。20 kHz 是可修改的调试起点，低速起转和温升须验证。

两板 nSLEEP 运行时必须为高；当前依赖模块硬件上拉/使能，不控制 PA8。先核对实际驱动板。电机1～4对应实际轮位、每轮正方向须架空确认。

## 编译与烧录

原 Keil 5 / ARM Compiler 5 工程 `user/rmcic.uvprojx` 保留。新增 GNU 构建入口，使用相同应用源码和仓库内标准外设库；GNU 启动文件由仓库 ST 中容量启动表适配，初始化 data/bss。链接限制仍为 STM32F103C8 的64 KiB Flash、20 KiB RAM，不利用探测器报告的额外 Flash。

```powershell
python build_firmware.py --toolchain '<Arm GNU工具链的bin目录>'
```

输出：`build/crtc-motor.elf`、`.hex`、`.bin`、`.map`。构建脚本只编译，不自动烧录。使用 STM32CubeProgrammer 的 SWD/ST-Link 接口下载 HEX，执行 Verify 后复位；CubeMX 是配置/生成工程工具。

## 验证与实车验收

电脑测试：

```powershell
$env:SANITIZE='0' # 仅当Windows GCC缺少UBSan运行库时使用
python tests/run_tests.py
```

测试覆盖八通道初始零输出与引脚分配、双定时器周期、四对输入独立性、正反向/零值/满量程/越界/NaN/无穷值、每次寄存器写入后的双输入互斥、换向及停车；保留256个回中判断、2197组混合、PS2逐位模拟与异常恢复测试。主机模拟不验证真实波形、电流和机械运动。

实车按顺序：
1. 架空轮子，上电确认无误转；手柄推杆上电不能启动，回中并松开按键后才能控制。
2. 先检查PS2模式0x73，再逐轮确认编号与正反方向；核对8路PWM及停止时低电平。
3. 低幅度测试前后、横移和转向，逐步加负载观察温升和供电；避免直接高速反转。
4. 测试关手柄、断DATA、断接收器电源、距离失联。无效帧会停车，但接收器重复返回有效旧帧仍无法识别无线失联。
5. 本次未实现夹爪、独立看门狗或故障硬件停机；夹爪TODO保留，其他限制仍未解决。

源码与板内原程序备份位于根目录 `backups/motor-drv8833-20260924-231908/`。历史 `upstream-changes.patch`、2026-09-15 审查记录仅用于追溯，当前源码与本说明优先。

## 本次连接与下载记录

2026-09-24 使用 xPack Arm GNU GCC 15.2.1 完成Cortex-M3编译和链接，程序Flash占用5304字节，静态RAM占用36字节，链接保留至少2 KiB栈。工具链位于本机 `C:/Users/15300/.codex/tools/crtc-arm-gcc/xpack-arm-none-eabi-gcc-15.2.1-1.1/bin`；下载包SHA256已与发布方校验文件核对。

STM32CubeProgrammer 2.23.0 经 ST-Link 写入、校验成功并复位，另行读回5304字节与BIN逐字节一致。ST-Link读取到Device ID=0x410、中容量STM32F1、目标电压3.26V；探测报告128 KiB Flash，构建仍按C8的64 KiB限制。板内原128 KiB Flash已备份为 `backups/motor-drv8833-20260924-231908/board-before.bin`。

复位后读回：TIM2/TIM3均启用，PSC=0、ARR=3599，八个CCR均为0；RCC寄存器与HSE/PLL 72 MHz配置一致。采样时 `control_ready=0`、PS2模式为0，尚未取得有效手柄帧。该结果证明固件已运行并配置定时器，不代表接收器、电机、波形或运动已经实测通过。完整记录见 [FLASH_RESULTS.txt](FLASH_RESULTS.txt)。

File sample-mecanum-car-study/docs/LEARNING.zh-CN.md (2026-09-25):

# 电控 B 阅读指引

先读 README.md，再按照 main.c → ps2.c → motor.c → pwm.c 阅读。原理不需要一次全部学完。

## 第一遍：main.c

从文件底部的 main 开始：
1. delay_init 准备延时，motor_init 内部调用 pwm_init，让 TIM2/TIM3 的八个输入从零占空比开始。
2. ps2_init 配置手柄通信引脚。
3. while (1) 每次调用 control_step，再等待 10 ms。
4. control_step 首先读一帧，返回无效就停止输出并清除按键历史。
5. 刚上电或刚从异常恢复时，必须松开按键、让左摇杆上下/左右和右摇杆左右回中，才能重新允许控制。
6. 正常后调用 buttons_process，然后调用 motor，把三个原始摇杆值交出去。

重要变量：
- ps2Data：这一轮手柄数据。
- control_ready：是否已经完成回中，可以接受运动指令。
- button_was_down：上轮各按键是否按下。
- last_released_button：最后一个松开的按键编号，255 表示尚无事件。

按钮保持原来的“松开时触发”，不在按住期间重复。先认识 switch，再把自己需要的非阻塞动作加到 on_button_released。叉键/圆键目前只是预留注释，没有夹爪程序。

## 第二遍：ps2.c

ps2_comm 的 8 次循环就是发送一个字节、同时接收一个字节。先看 bit=0，然后 bit=1，直到 bit=7，观察 bit_mask 如何选中当前位。

ps2_read 总共交换 9 个字节，然后检查模式和固定标志；有效时把后面的字节放入结构体。返回值是“1 有效 / 0 无效”；这是相对上游的接口变化。

在 Keil Watch 中观察 ps2Data 四个轴和两组按钮。工程没有 printf/串口发送功能，因此不能只加 printf 就默认电脑能看到数据。

## 第三遍：motor.c

motor 参数依次是：左摇杆上下、左摇杆左右、右摇杆左右，仍用 0～255 原始值。

示例（保持原项目的编号和方向约定）：

| 调用 | 四轮带符号输出比例 |
|---|---|
| motor(128,128,128) | 0, 0, 0, 0 |
| motor(0,128,128) | +0.5, +0.5, +0.5, +0.5 |
| motor(128,0,128) | +0.5, -0.5, -0.5, +0.5 |
| motor(128,128,0) | -0.4, -0.4, +0.4, +0.4 |
| motor(0,0,0) | +3/7, -2/7, +2/7, +1 |

120～136 的摇杆数值视为回中。输出是开环驱动比例，并不是每分钟转数；不要用输出变量冒充实际测速反馈。

“同时平移和旋转”时可能超过 1，四轮一起除以最大绝对值才可以保留比例。先用上表算一遍，再展开 pwm_set 调用。

最后的 pwm_set1～4 接收带符号输出，每个电机占用相邻两个 PWM 通道。正向为 PWM/0，反向为 0/PWM，零值为 0/0 滑行。换向先清旧方向再给新方向，不是机械减速斜坡。

## 第四遍：pwm.c

周期共有 PWM_PERIOD_COUNTS 个计数，计数器从 0 数到 PWM_PERIOD_COUNTS-1。PWM1 中计数器小于 CCR 时输出高电平：
- CCR=0：0%。
- CCR=1800：50%。
- CCR=3600：100%。

注意只有 ARR/PSC 寄存器参数按计数规则减 1；占空比计算不再减 1。

正常 72 MHz 定时器时钟下，PSC=0、ARR=3599，对应 20 kHz；这是初始调试参数，实测低速和温升后再调整。TIM4 留给舵机。

## 没有板子时的练习

电脑有 Python 3 与 GCC 时，在项目根目录执行：

```sh
python3 tests/run_tests.py
```

测试使用项目真实的 C 计算和控制代码，但把电信号与定时器操作模拟出来。读 tests 不是前置任务；先学懂 hardware 下四个文件即可。

拿到板子后，需要在 Keil 里完整编译，并先验证手柄数据和输出波形，再由电控 A 完成单轮架空测试。与接收器有关的失联、模式和电平限制见 REVIEW.zh-CN.md。

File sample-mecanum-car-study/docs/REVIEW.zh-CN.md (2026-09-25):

# 源码检查与修改记录

> 下文保留 2026-09-15 的历史审查记录。2026-09-24 已完成 DRV8833、20 kHz 和 PS2 接线适配，当前实现及验证以 [DRV8833 说明](DRV8833.zh-CN.md) 为准；下文“将来要改”描述的是旧版状态。

检查日期：2026-09-15。上游：[Serialist/sample-mecanum-car](https://github.com/Serialist/sample-mecanum-car)。
克隆基线：`1fa85bbdcd6c62f33f871284b642959cea975805`；本地分支：`study-readable-fixes`。

这是一份供电控新手学习的修改版。保留 STM32F103C8T6、标准外设库、Keil 5 / ARM Compiler 5 工程，以及 L298N 的引脚、四轮编号和原运动组合。没有适配 DRV8833，也没有加入轮速 PID、舵机控制或串口打印。

## 检查范围

逐一检查 hardware 下的 6 个 C 源文件和头文件，并检查 Keil 工程、启动文件选择、系统时钟配置及涉及的标准库接口。第三方 CMSIS/标准外设库不是本次全面审计对象，保持原文件内容。

## 已修复或澄清

| 发现 | 影响 | 本版处理 |
|---|---|---|
| PWM 原公式为 duty * ARR - 1 | 零输入得到 -1，随后浮点转 uint16_t 超出可表示范围；可能产生错误输出 | 先限制输入，再计算 duty * PWM_PERIOD_COUNTS；零输入直接返回 0，1 对应完整周期计数数 |
| 四轮混合最大可到 1.4 | 超出 0～1 的 PWM 预期，逐轮硬截断又会改变比例 | 找到四轮最大绝对值；仅超过 1 时四轮同时除以它，PWM 层再作兜底限幅 |
| 摇杆没有中心死区 | 回中偏差会造成输出 | 中心 128、死区 ±8，死区内归零，区外连续映射到 ±1，端点两侧分别计算分母 |
| 模式错误时不更新电机 | 旧的比较寄存器和方向继续有效 | ps2_read 返回有效标志，失败立即调用 motor_stop，不处理按键 |
| 原始包没有固定标志检查 | 错位/异常数据容易被当成命令 | 检查模式 0x73 和固定字节 0x5A；失败清空按键、摇杆回中 |
| 原按键逻辑先于模式检查执行 | 通信异常可能伪造一次松开事件 | 只对有效帧处理按键，异常时清除所有历史按键状态 |
| 上电/恢复后推杆状态会直接生效 | 操作者可能未准备好，车即开始驱动 | 等待控制用的三个摇杆轴回中且全部按键松开，下一轮才接受运动 |
| motor_init 没有独立开启 GPIOA 时钟 | 暗中依赖 pwm_init 的调用顺序 | motor_init 自己开时钟，方向脚预置低；启动 PWM 时初始 CCR 为零 |
| 原先先更新 PWM、再改变方向 | 新幅度可能短暂与旧方向组合；反转直接带旧输出 | 保留 L298N 接口，更新方向前先将 EN 的 PWM 清零，随后写方向和新 PWM；未实现动态反转缓冲 |
| PWM 频率注释错误 | 容易把 50 Hz 误认为 20 kHz | 更正注释。正常 TIM3 时钟 72 MHz、PSC=71、ARR=19999，实际 50 Hz；按“电机暂不改”保留数值 |
| PS2 通信循环依赖 8 位移位溢出退出 | 对新手不直观 | 改为 bit 从 0 到 7 的固定 8 次循环，仍低位先传 |
| PS2 初始化只预设 CS | CMD/CLK 初始化电平不明确 | 在切换 GPIO 输出前将 CMD、CS、CLK 预设高；选中及字节之间留短延时 |
| ps2.h 写 PA4～PA7，但源码使用 PB12～PB15 | 按注释接线会接错 | 统一注释；按钮改用标准 SELECT/L3/R3/圆/叉等名称，实际兼容手柄丝印需核对 |
| 函数指针数组 16 项全部是 temp | 阅读困难且没有真实按键动作 | 改为单次循环 + on_button_released 中的 switch；保留“松开时触发”语义，记录 last_released_button 供调试 |
| 头文件彼此包含 main.h | 依赖关系绕、无关代码互相牵连 | 模块头只声明自己的接口，源文件按需包含库；sys.h 保留兼容但主控制代码已不使用位带宏 |
| pwm_set5/6/7 有声明无实现，MOTOR_NO_PID 宏没被使用 | 容易误以为有额外舵机通道或可切换 PID | 移除这些误导性声明/宏，未凭空补功能 |
| delay_us 用固定 9 倍计数且未处理 0 | 暗中依赖 72 MHz；0 延时存在计数异常风险 | 初始化时读取 SystemCoreClock，用 HCLK 计数，LOAD=ticks-1，零延时直接返回；长毫秒延时分成 1 ms |
| Keil 的时钟元数据为 12 MHz，源码假设 HSE=8 MHz | 工程信息与源码不一致 | 工程元数据对齐 8 MHz，同时删除不存在的 include 路径；真实晶振仍需实物确认 |
| 上游留有历史 Listings/map | 容易误当作本版构建结果 | 交付压缩包排除这些旧构建记录和个人 IDE 状态文件 |

关于 PWM 零值的严谨表述：C 语言中，-1.0 浮点数直接转换成 uint16_t 超出范围，属于未定义行为；不能保证在所有编译器上都恰好变成 65535。可以确认的是：该公式错误，不能用作零输出。

## 为初学者保留的阅读结构

1. main.c：主循环、有效帧判断、回中条件、按键 switch。
2. ps2.c：GPIO 初始化、固定 8 位通信、9 字节包的拆解。
3. motor.c：死区映射、四轮组合、整体缩放、L298N 输出。
4. pwm.c：定时器配置、占空比到 CCR 的换算。

没有引入 RTOS、回调框架或多层驱动抽象。新手可以先把一个函数当作整体使用，再逐层展开。

## 还没有解决的实物问题

### 无线失联识别并不完整

现在能检测的是 STM32 读到的模式/标志不符合要求。数据包没有本程序可使用的校验和、无线链路心跳或序号；某些接收器在手柄关机后可能继续返回格式正确的旧数据，这种情况本版无法识别。

因此不能把“错误包停车”称为“任何无线失联都能停车”。后续必须实际测试关手柄、断开接收器 DATA、拔接收器供电和距离失联。不得仅以“连续数据不变”作为失联依据，因为持续推杆本来也可能产生相同数据。代码位置：main.c 的 TODO_LINK_LOSS。

### 模式与通信兼容性

ps2_init 只设置 GPIO，不发送完整的模拟模式配置序列。先尝试手柄上的 MODE/ANALOG 切换，以实际 mode 值 0x73 为准，不用指示灯颜色判断。0x41 和 0x79 均拒绝。所加的固定微秒延时不是 ACK 握手；兼容接收器的时序、电平和供电仍须看卖家资料与实测。

### 电机与机械方面

保留旧 L298N 引脚和原四轮正负号，未确认 1～4 对应实车哪个轮子。50 Hz 只是继承原工程，不代表适合你们的 TT 电机。没有编码器反馈、轮速闭环、起步/反转斜坡，也没有最大电流控制。motor_stop 撤掉驱动，车可能因惯性继续滑行。DRV8833 适配步骤见下节。

### 主循环卡死与硬件异常

当前故障异常处理函数停在死循环，硬件 PWM 可能继续运行；本版没有加独立看门狗或硬件停机线。此事需要与整车电控设计一起完成。原系统时钟启动也存在等待 PLL 的循环。main.c 的 TODO_WATCHDOG 是后续入口；仅靠读取函数返回值不能处理这些情况。

SysTick 当前被阻塞延时独占，不能同时用作 RTOS 或周期中断时基；也不能在中断中重入 delay_us。未来增加耗时夹爪动作应采用逐次推进的状态逻辑，避免长时间 delay 导致遥控无法更新。

## DRV8833 将来要改哪里

在编辑器全项目搜索 `TODO_DRV8833`。

| 位置 | 将来要改的内容 |
|---|---|
| motor.c / motor_init | 按新模块的实际双输入接口分配 GPIO/PWM 引脚，确认是否有 nSLEEP |
| motor.c / l298n_set_direction | 旧 IN1/IN2 + EN 模式不能直接套用，改成 DRV8833 双输入真值表 |
| motor.c / motor 的最后一段 | 将每轮带正负号的输出转换成新驱动实际需要的双输入信号 |
| motor.c / motor_stop | 明确新驱动的滑行和制动状态 |
| pwm.c / pwm_init | 根据通道数量和接线重新分配定时器、复用引脚 |
| pwm.h | 结合 TT 电机和驱动实测选择频率、输出上限；不要直接使用占位经验值 |

本次对 motor.c 的修改是算法修复、命名和旧接口的输出顺序整理，没有将电机驱动换成 DRV8833。与电控 A 对接时应先约定轮子编号、接线和符号。

## 验证结果与限制

已在 Linux / GCC 上执行 `python3 tests/run_tests.py`，记录见 TEST_RESULTS.txt：

- 全部 6 个应用 C 源文件使用仓库内的真实 STM32 头文件通过 C99 语法检查，启用 -Wall -Wextra -Werror。
- 主控制、PS2、电机和 PWM 的实际 C 代码参与主机测试；仅 GPIO、定时器操作和延时由测试桩代替。
- 验证 PWM 零/小数/满量程/越界/NaN/无穷输入。
- 验证 256 个回中判断、死区边缘、2197 组平移/旋转组合、四轮比例和方向；检查改变方向之前 PWM 已归零。
- 通过逐位模拟验证 LSB 先传、请求内容、256 种接收字节、字段顺序及无效数据清除。
- 验证启动推杆、错误模式、错误标志、恢复回中、16 个按键的松开事件及断连不产生虚假松开。
- 启用 UndefinedBehaviorSanitizer 和浮点转整数越界检查。
- 检查 Keil 项目列出的源文件和包含目录均存在。

未安装 Keil/ARM Compiler 5，也未获得 ARM 目标编译器；没有进行完整 MCU 编译、链接或烧录。主机测试没有验证真实 SysTick 延时、GPIO 电平/时序、PWM 波形、电流或运动效果，不提供声称可直接烧录的 HEX。

## 本地工程与差异

Keil 工程：user/rmcic.uvprojx。它仍选择 ARM Compiler 5.06 和 STM32F1xx DFP；若只安装 Compiler 6，不要把“Keil 5 IDE”误认为已经包含 Compiler 5。源码使用 UTF-8 中文注释。

可用 git diff 查看本地变更；压缩包中的 docs/upstream-changes.patch 记录对原有应用源码、头文件和工程文件的修改。新增 README、文档和主机测试直接包含在压缩包中。

LICENSE 及已有第三方来源/版权声明保留。压缩包不含 .git、旧 Listings/map、旧个人 IDE 状态，也不含未经验证的二进制固件。

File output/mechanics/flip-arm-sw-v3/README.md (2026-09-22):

# 舵机照片适配 v3 — 2026-09-21

根据项目`pic/`中的8张实物尺照微调v2，保留原料仓、臂长及三个工作姿态。使用SolidWorks 2026生成原生零件、装配及STEP；v2保留。

## 照片依据

MG995：`197`长向及安装耳、`198`高度、`199`端部及标签、`200`宽向。SG90：`201`长向、`202`高度及标签、`203`耳孔、`204`宽向；编号对应文件名倒数第二组数字。两只标签均为TIANKONGRC，分别写MG995和SG90 ANALOG。

尺子与物体存在距离和透视差；以下取整用于拟合外形，不当作卡尺测量结果。

| 项目 | v3建模值/mm | 依据 |
|---|---:|---|
| MG995主体长×宽 | 40.5×20 | 沿用用户此前商品参数，照片量级一致 |
| MG995含耳总长 | 54.5 | 照片约54–55，拟合值 |
| MG995主壳高度/含凸台和轴总高 | 35 / 42 | 照片估读与分层拟合；不把旧商品39.5无条件解释为主壳高 |
| MG995耳位置/厚度 | 主壳底起25 / 3 | 暂定分层，用于安装外形 |
| MG995耳孔中心距 | 47×10 | 参考孔位，未由照片确认精确孔心 |
| SG90主体长×宽×主壳高 | 23×12×22 | 照片约23、12、22量级 |
| SG90含耳长/含轴高 | 32 / 29 | 照片拟合值 |
| SG90耳位置/厚度 | 主壳底起16 / 2 | 暂定分层 |
| SG90耳孔距 | 28 | 参考值，托架采用可调槽 |

输出轴建成光圆包络，未打印或复刻花键；实际使用原装舵盘。照片没有给出可确认的舵盘孔距，因此不据此冻结联轴器舵盘孔。

## 修改内容

- MG995补安装耳、四个参考孔、上盖凸台和输出轴；修正朝向，让输出轴朝向臂根联轴器。
- MG995支架横向位置从Z48改为Z53，使支架面Z59与安装耳面相接；支架脚深24改为17，落在原底板宽度内。
- 同步底座孔：轴承支架脚孔为X±20/Z±14；舵机架脚孔为X=-9、31/Z=57、66（X相对臂轴）。底盘原板安装槽位置仍待核对。
- 仓前角避让槽随MG995安装耳和支架位置扩大为17mm横向宽、58mm高，保持其余仓体尺寸。
- 原夹爪方块占位换为SG90外形，新增3mm厚托架，窗口23.8×12.8，耳孔用2.4×4调整槽。
- SG90位于腕部侧面，壳体与腕部垫块之间留出空间。托架至腕部的连接件、原装舵盘至夹指的连杆尚未完成；现有夹指仍是动作外形，不是已驱动夹爪。

## 使用与验证

打开`FlipArm_V3_deposit.SLDASM`看投料；另有pickup、raised装配。保留同目录所有SLDPRT，或使用单文件STEP。`V3_REF`为采购件参考外形，不是打印零件；`V3_08_SG90_mount`为安装托架草案。

`build.ps1`用Windows PowerShell运行，`build.cs`是当前生成源码。重建读取本目录中从v2复制的其余零件，仅生成已修改零件及三个装配；会覆盖当前输出，先备份。`prepare.py`用于从v2重新生成源码，不应覆盖后续手动修改。

查看`build-log.txt`的实体数量、特征错误与导出结果，`*.png`为SolidWorks视图。软件检查不等于完整运动干涉或载荷验证。料仓内180×143×80、底68、沿148；臂轴110、臂板孔距130保持原值。

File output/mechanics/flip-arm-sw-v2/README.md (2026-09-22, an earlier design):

# 翻转臂与料仓装配草案 v2

在SolidWorks 2026中建立可编辑零件，输出夹取、抬升、投料三份固定姿态装配及STEP。旧v1保留。当前是空间布局与接口草案，夹爪是占位外形，未建立SG90驱动连杆、运动配合或整车收拢姿态，不作为整套可直接打印装车的完成件。

## 本版参数（mm）

| 项目 | 数值与依据 |
|---|---|
| 底盘 | 用户提供255.8×149；板厚3、上表面离地35暂作占位 |
| 车轮 | 用户提供外径60；宽28、位置为占位，未复刻麦轮滚子 |
| 电控空间 | 150×90×25包络，放在底盘与仓底之间；不是具体电路模型 |
| 料仓 | 内180×143×80，侧壁和底板厚3，外长186、宽149 |
| 仓底/仓沿 | 内底离地68、仓沿148，沿用叠层估算，不额外叠加裕量 |
| 臂轴 | 距车头35，离地110；支架从离地40起高70 |
| 臂板 | 两片，轴至腕部孔中心130，主体宽22、厚6 |
| 名义夹持中心 | 臂轴至方块中心150，含暂定夹爪伸出20 |
| 舵机 | MG995主体40.5×20×39.5，来自用户商品截图；安装耳、轴位置和舵盘孔仍为参考值 |
| 支承 | 5mm钢轴、两只625ZZ轴承的参考方案；不是打印轴或打印轴承 |

世界坐标X从车头向车尾，Y向上，Z为横向。料仓位于X=69.8…255.8，后部和侧部用于接料，收集网暂不加入。容量目标12–16块；整齐排列每层4×3=12块是几何计数，不等于散装验证结果。

仓前板靠舵机支架处增加8mm宽、从仓底外表面向上58mm的局部避让槽，避开现有支架前角；不改变后方和侧方接料口。该槽不是供40mm方块通过的开口。

## 三个姿态

| 文件 | 臂角（相对向后水平） | 方块中心X/Y |
|---|---:|---:|
| `FlipArm_V2_pickup` | 216.87° | -85 / 20 |
| `FlipArm_V2_raised` | 90° | 35 / 260 |
| `FlipArm_V2_deposit` | 60° | 110 / 239.9 |

夹取至投料的名义转角156.87°；并非舵机已校准的脉宽或实际行程。夹爪姿态随臂旋转，方块为40mm实心包络，用于检查空间，不替代官方镂空块。

投料姿态方块X投影约83.75…136.25，位于仓内X=72.8…252.8范围，最低点约213.66，高于仓沿148。臂板在仓前沿处的下边缘计算高度约148.28，属于接近相切的布局；需要实际夹爪确定后再调整。这是选定姿态的解析检查，不是连续运动干涉检测或物理仿真。

## 文件使用

- 优先打开`FlipArm_V2_deposit.SLDASM`看整体，所需SLDPRT必须保留在同目录。组件固定在各展示姿态，不能当成已约束运动机构拖动。
- 三个同名STEP为独立交换文件。`V2_01`至`V2_07`是机构草案零件，`V2_REF`开头为采购件或外形占位。
- `build-log.txt`记录各零件实体数量及导出结果；`*.png`为SolidWorks实际视图。
- 参数和几何在`build.cs`，通过`powershell.exe -NoProfile -File .\build.ps1`重建；操作前备份。`prepare.py`从旧v1生成初稿源码，会覆盖build.cs，后续修改应以build.cs为准。

尚需完成的加工接口：底盘安装孔、支架与底座孔位配套、舵机耳及舵盘、轴向限位、实际夹爪连接。此次未核定初始260×190×200mm收拢包络、满仓过桥、载荷强度、电控实际高度或真实车轮外宽；不能把展示姿态当作已通过这些检查。

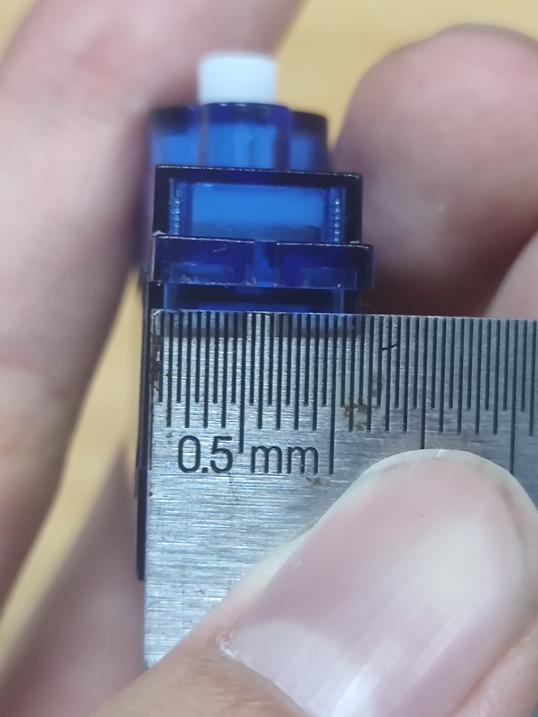
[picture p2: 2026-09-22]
pic/微信图片_20260921121214_204_23.jpg

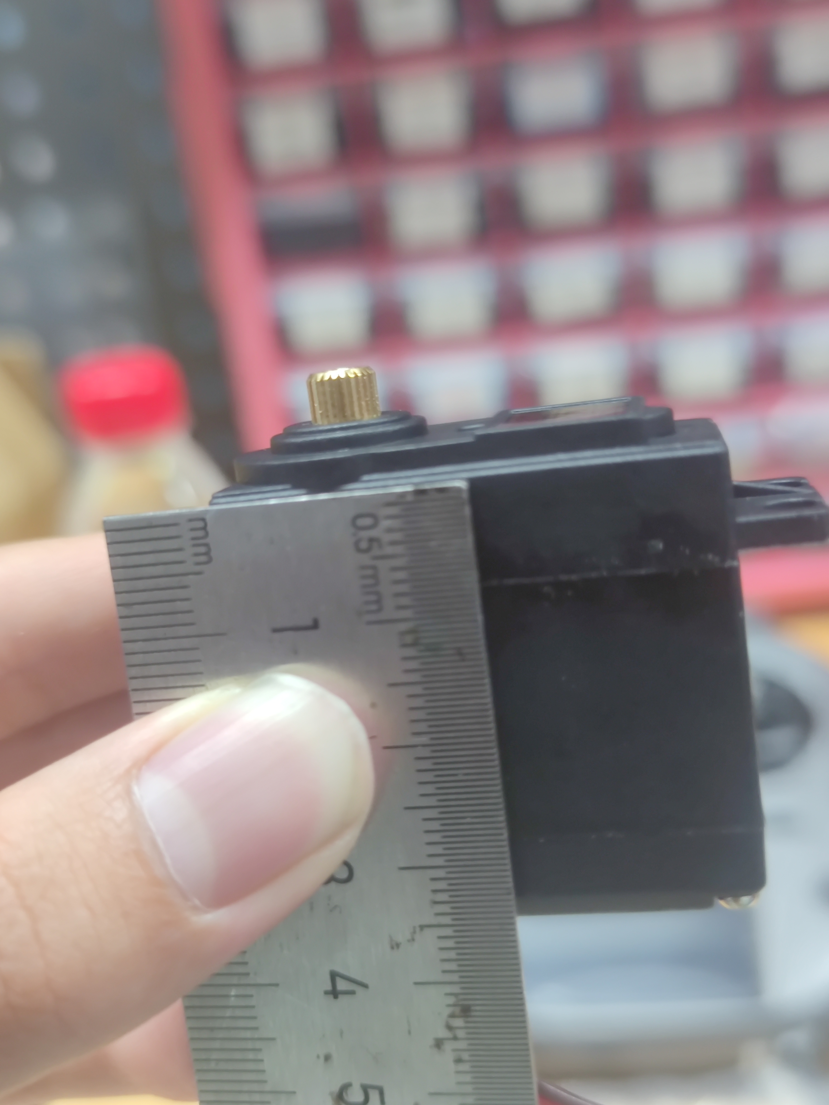
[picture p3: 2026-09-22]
pic/微信图片_20260921121127_198_23.jpg

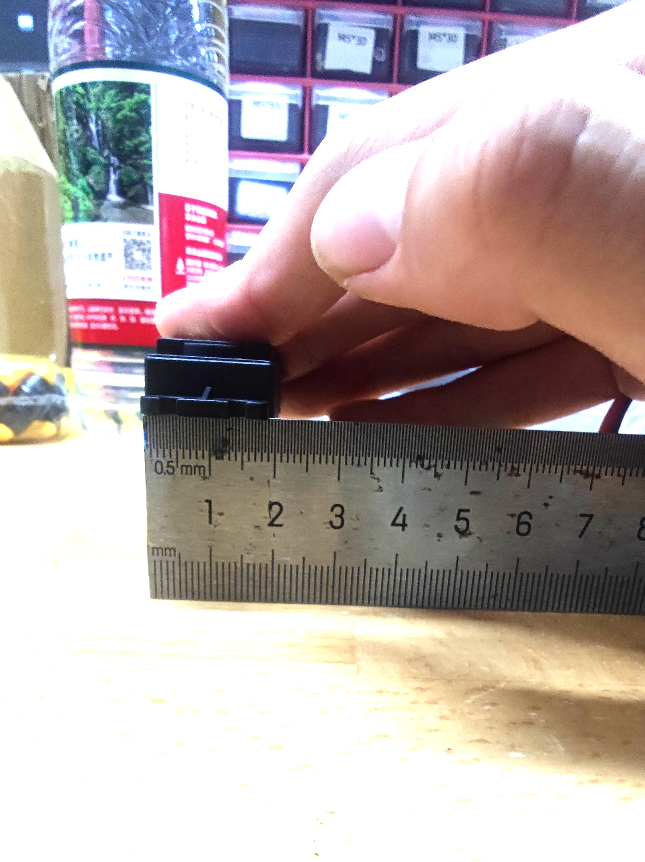
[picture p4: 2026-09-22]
pic/微信图片_20260921121150_200_23.jpg

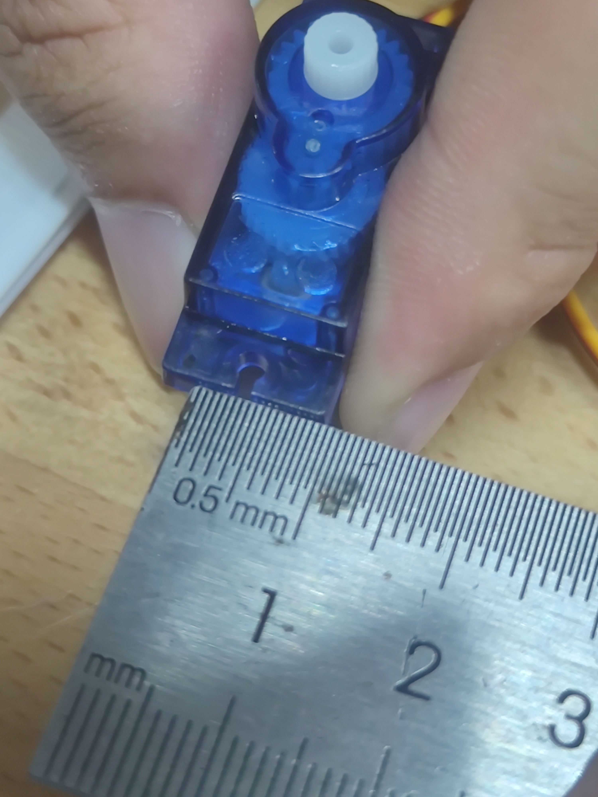
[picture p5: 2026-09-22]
pic/微信图片_20260921121208_203_23.jpg

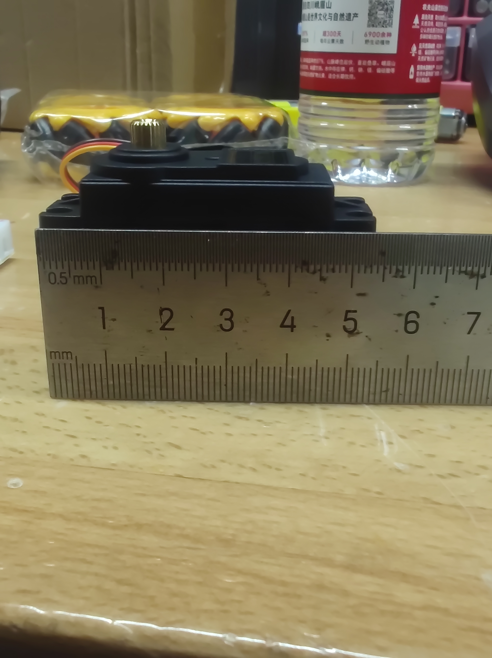
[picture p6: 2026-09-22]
pic/微信图片_20260921121124_197_23.jpg

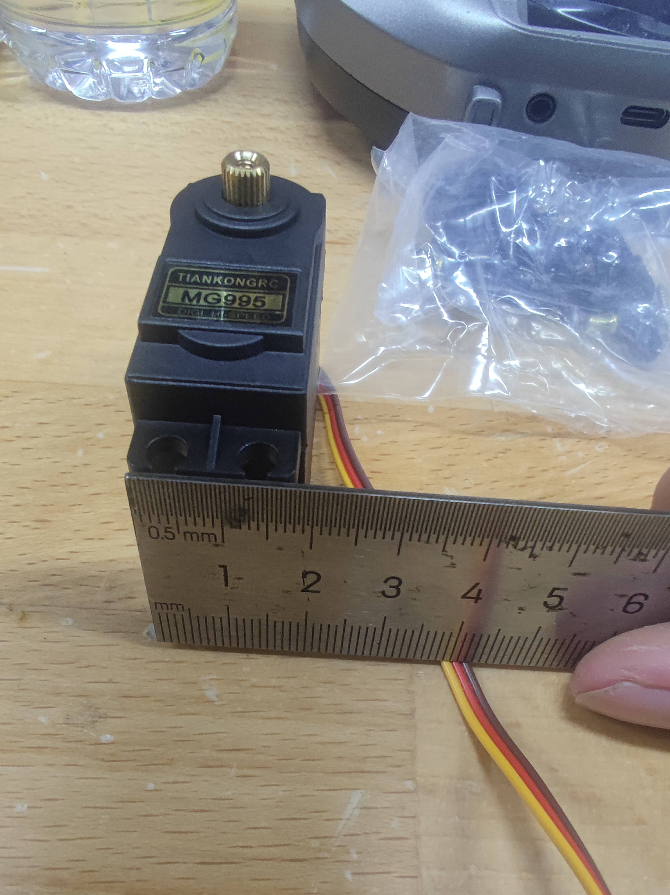
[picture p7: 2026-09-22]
pic/微信图片_20260921121137_199_23.jpg

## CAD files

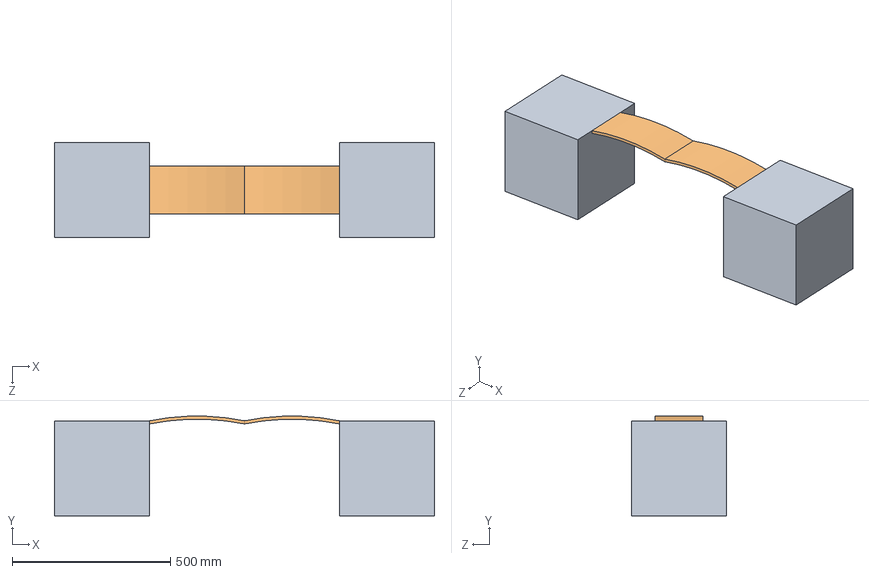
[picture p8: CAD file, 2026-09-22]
output/mechanics/bridge-platforms-v2/Bridge_with_platforms_TEST.STEP
1200.0 x 314.4 x 300.0 mm
Platform_300x300x300 x 2
Bridge_segment_for_platforms x 2

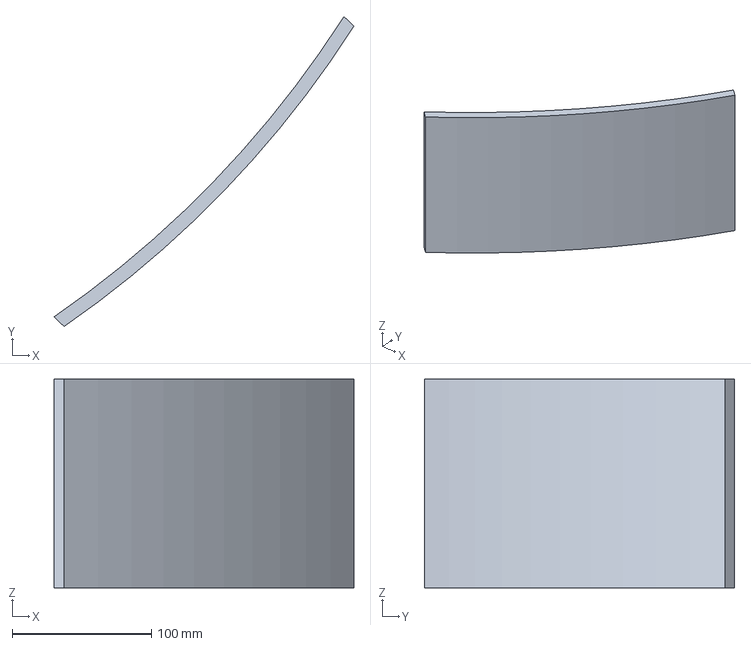
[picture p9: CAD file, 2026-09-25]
output/mechanics/bridge-test-v1/Bridge_K1Max_PLA_028_10pct.3mf
215.5 x 222.8 x 150.0 mm

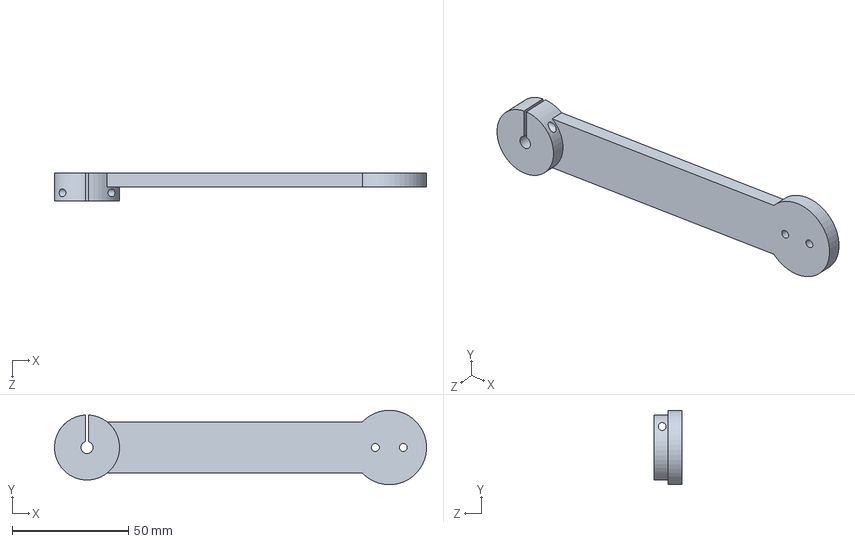
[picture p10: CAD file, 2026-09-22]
output/mechanics/flip-arm-sw-v3/V3_04_arm_plate.SLDPRT
159.9 x 32.0 x 12.0 mm

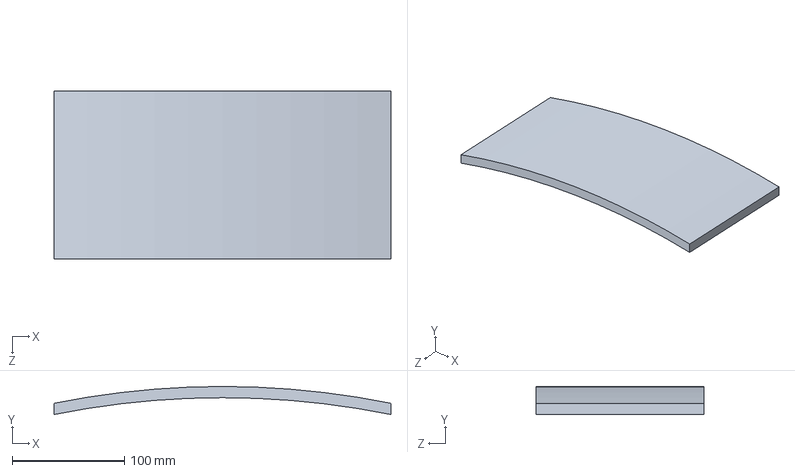
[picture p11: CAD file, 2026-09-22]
output/mechanics/bridge-platforms-v2/Bridge_segment_for_platforms.SLDPRT
300.0 x 25.0 x 150.0 mm

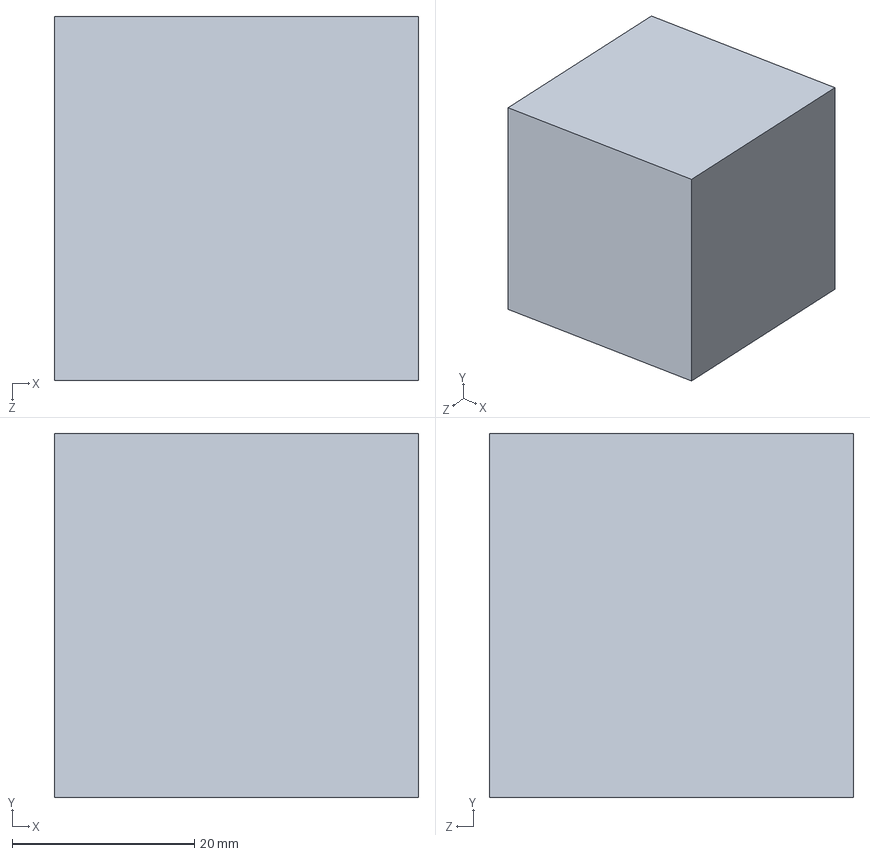
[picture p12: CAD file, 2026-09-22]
output/mechanics/flip-arm-sw-v3/V3_REF_block40.SLDPRT
40.0 x 40.0 x 40.0 mm

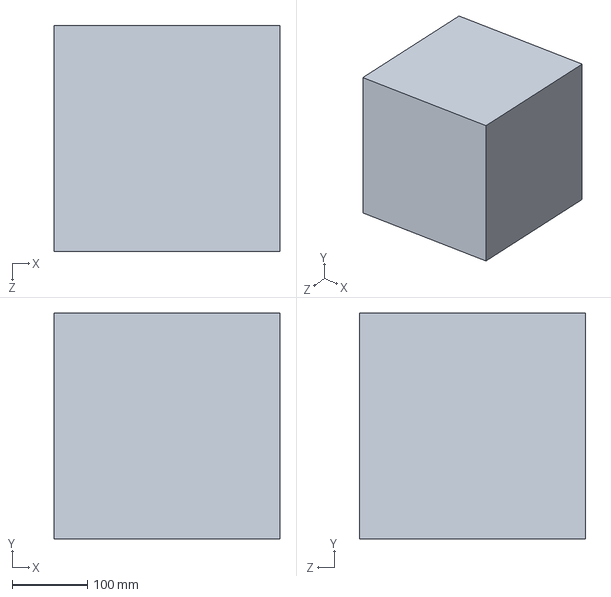
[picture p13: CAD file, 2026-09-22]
output/mechanics/bridge-platforms-v2/Platform_300x300x300.STEP
300.0 x 300.0 x 300.0 mm

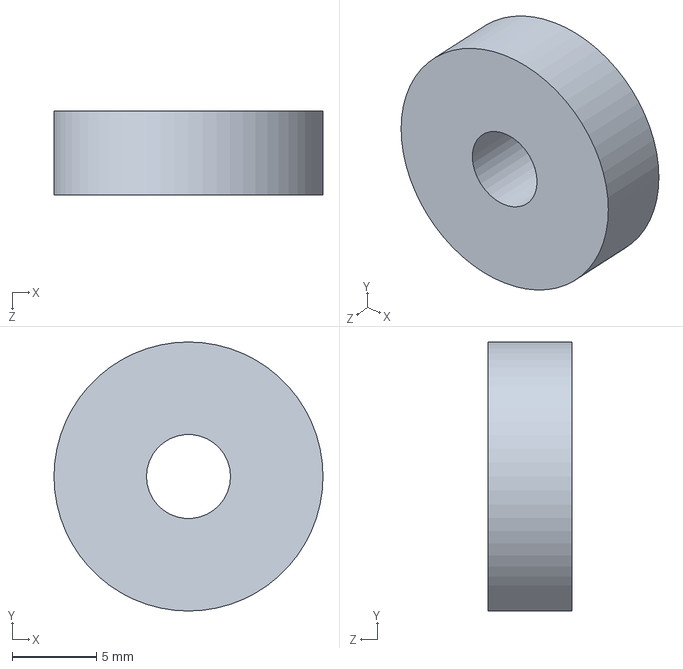
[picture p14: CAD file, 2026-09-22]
output/mechanics/flip-arm-sw-v3/V3_REF_625ZZ.SLDPRT
16.0 x 16.0 x 5.00 mm

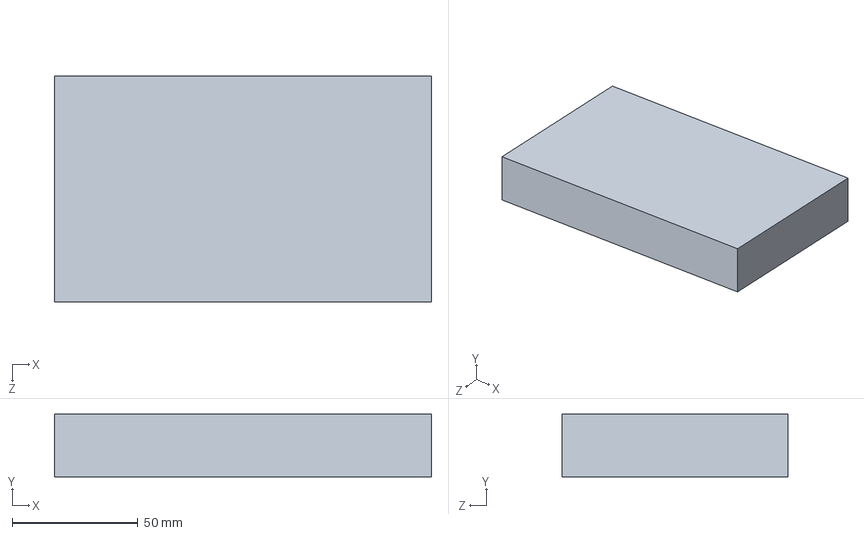
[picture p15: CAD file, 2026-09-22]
output/mechanics/flip-arm-sw-v3/V3_REF_electronics_envelope.SLDPRT
150.0 x 25.0 x 90.0 mm

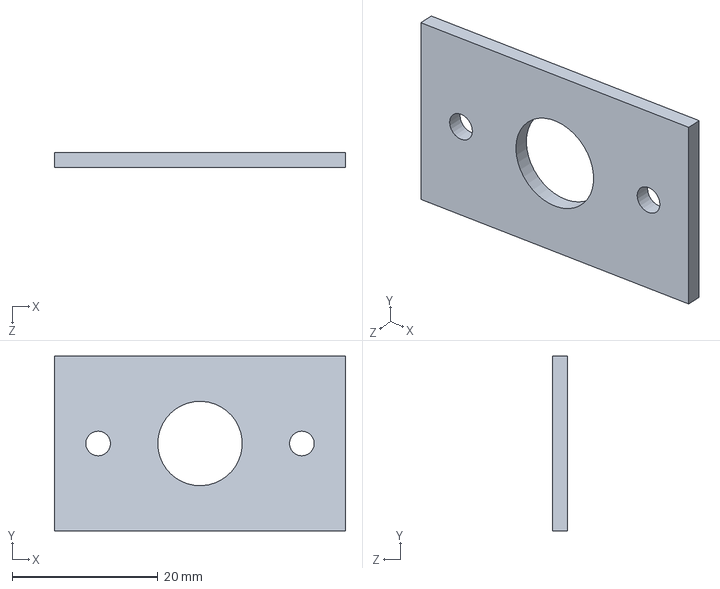
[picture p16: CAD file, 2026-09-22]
output/mechanics/flip-arm-sw-v3/V3_03_bearing_retainer.SLDPRT
40.0 x 24.0 x 2.00 mm

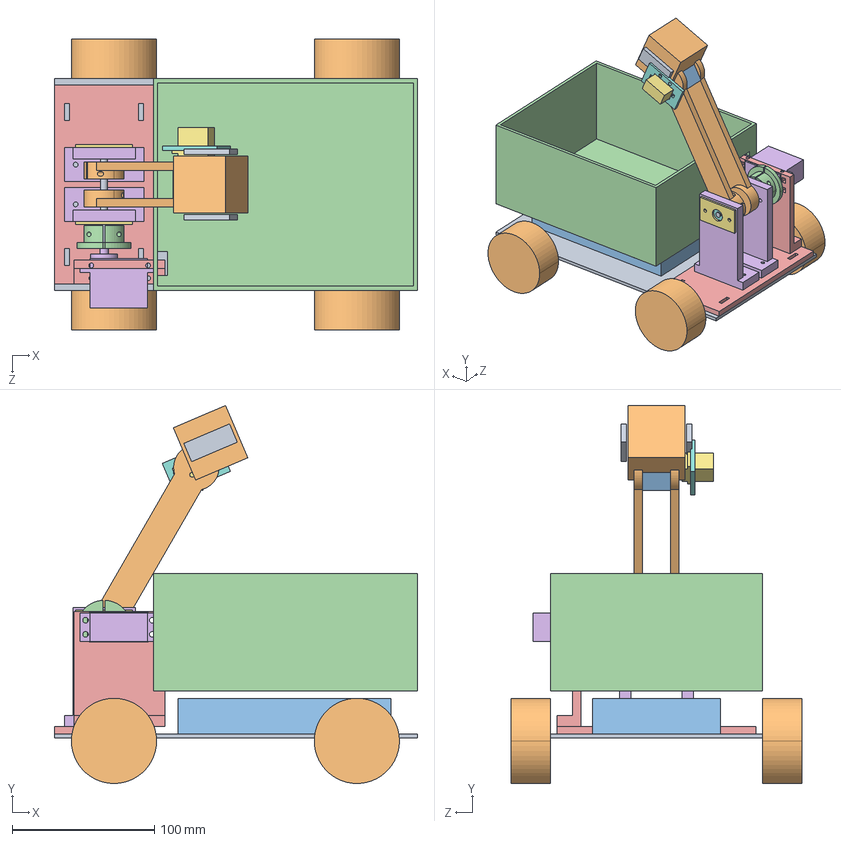
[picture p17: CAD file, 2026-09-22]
output/mechanics/flip-arm-sw-v3/FlipArm_V3_deposit.STEP
255.8 x 266.2 x 205.0 mm
V3_REF_chassis_255p8x149
V3_REF_wheel_D60 x 4
V3_REF_electronics_envelope
V3_bin_180x143x80
V3_01_base
V3_02_bearing_tower x 2
V3_03_bearing_retainer x 2
V3_REF_625ZZ x 2
V3_REF_5mm_shaft
V3_04_arm_plate x 2
V3_05_wrist_adapter
V3_06_horn_coupler
V3_07_servo_stand
V3_REF_MG995_envelope
V3_REF_SG90
V3_08_SG90_mount
V3_REF_gripper_finger x 2
V3_REF_block40

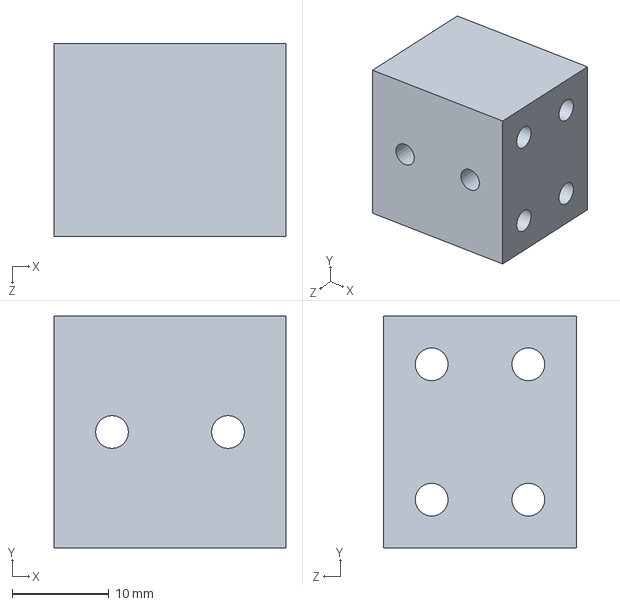
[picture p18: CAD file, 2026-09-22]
output/mechanics/flip-arm-sw-v3/V3_05_wrist_adapter.SLDPRT
24.0 x 24.0 x 20.0 mm

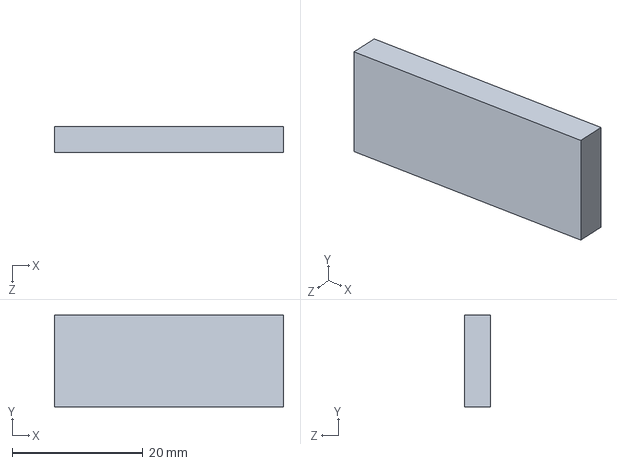
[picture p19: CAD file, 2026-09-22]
output/mechanics/flip-arm-sw-v3/V3_REF_gripper_finger.SLDPRT
35.0 x 14.0 x 4.00 mm

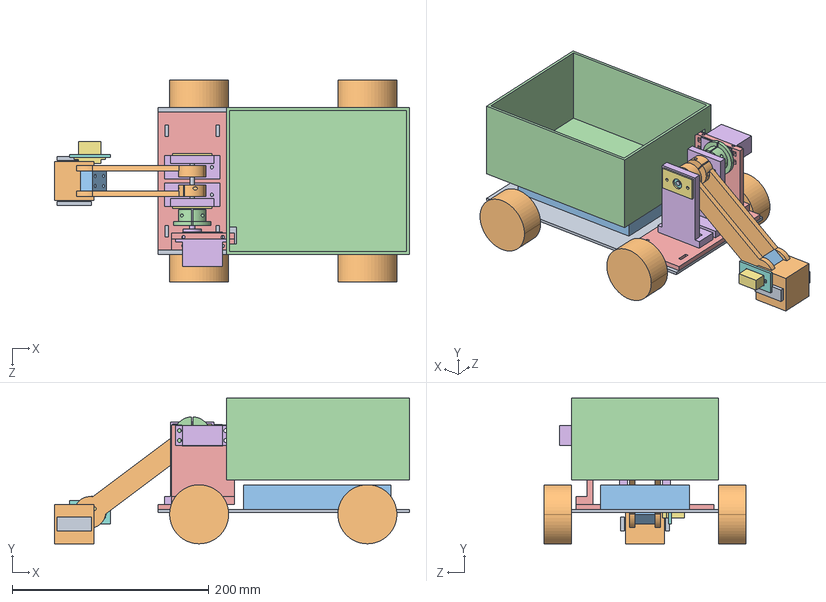
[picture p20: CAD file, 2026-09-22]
output/mechanics/flip-arm-sw-v3/FlipArm_V3_pickup.STEP
360.8 x 148.0 x 205.0 mm
V3_REF_chassis_255p8x149
V3_REF_wheel_D60 x 4
V3_REF_electronics_envelope
V3_bin_180x143x80
V3_01_base
V3_02_bearing_tower x 2
V3_03_bearing_retainer x 2
V3_REF_625ZZ x 2
V3_REF_5mm_shaft
V3_04_arm_plate x 2
V3_05_wrist_adapter
V3_06_horn_coupler
V3_07_servo_stand
V3_REF_MG995_envelope
V3_REF_SG90
V3_08_SG90_mount
V3_REF_gripper_finger x 2
V3_REF_block40

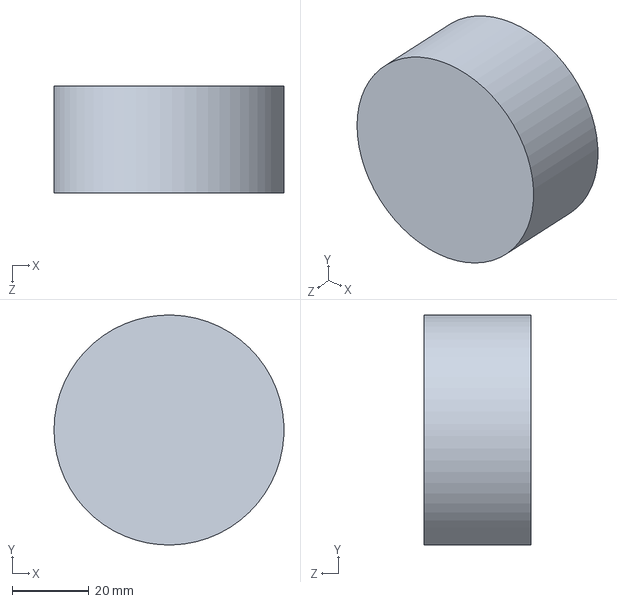
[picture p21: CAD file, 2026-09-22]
output/mechanics/flip-arm-sw-v3/V3_REF_wheel_D60.SLDPRT
60.0 x 60.0 x 28.0 mm

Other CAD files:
output/mechanics/bridge-test-v1/Bridge_TEST_300x150_R15_T10.STEP
output/mechanics/flip-arm-sw-v3/V3_07_servo_stand.STEP
output/mechanics/flip-arm-sw-v3/V3_01_base.STEP
output/mechanics/bridge-platforms-v2/Bridge_with_platforms_TEST.SLDASM
output/mechanics/bridge-platforms-v2/Platform_300x300x300.SLDPRT
output/mechanics/bridge-test-v1/Bridge_TEST_300x150_R15_T10.STL
output/mechanics/flip-arm-sw-v1/01_base.SLDPRT
output/mechanics/flip-arm-sw-v1/01_base.STEP
output/mechanics/flip-arm-sw-v1/02_bearing_tower.SLDPRT
output/mechanics/flip-arm-sw-v1/02_bearing_tower.STEP
output/mechanics/flip-arm-sw-v1/03_bearing_retainer.SLDPRT
output/mechanics/flip-arm-sw-v1/03_bearing_retainer.STEP
output/mechanics/flip-arm-sw-v1/04_arm_plate.SLDPRT
output/mechanics/flip-arm-sw-v1/04_arm_plate.STEP
output/mechanics/flip-arm-sw-v1/05_wrist_adapter.SLDPRT
output/mechanics/flip-arm-sw-v1/05_wrist_adapter.STEP
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

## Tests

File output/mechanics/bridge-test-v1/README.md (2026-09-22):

# 150mm桥面通行试验模型

用途：验证现有轮胎外侧间距大于150mm、内侧间距小于150mm的底盘能否靠部分胎面稳定通过。不含两端高台、支架或护栏。不是官方场地精确复刻，也不是承载强度已验证的打印设计。

## 文件

- `Bridge_TEST_300x150_R15_T10.SLDPRT`：SolidWorks 2026原生实体，圆弧截面草图＋150mm拉伸。
- 同名`.STEP`：精确曲面交换文件，优先用于后续CAD加工。
- 同名`.STL`：毫米网格，已核对外包络300×150×25mm；竖直方向在CAD中为Y，切片时旋转并落到平台，切勿缩放适配打印机。
- `preview.png`：SolidWorks导出的模型视图。
- `build.cs` / `build.ps1`：参数及重建脚本。Windows PowerShell运行`powershell.exe -NoProfile -File .\build.ps1`，需要安装SolidWorks 2026。重建会覆盖本目录同名导出文件；修改前备份。
- `verification.txt`：实体数量、特征错误、极值坐标和导出结果。

## 尺寸依据与边界

本地《CRTC2026规则文档v1.0》第15页：单段长300mm、宽150mm、净高130mm、矢跨比0.05。b4/c4两段相接，另一侧f5/g5两段相接。本文件只做一个300mm模块，不能用单段测试替代整条桥的连续通行。

| 参数 | 本版取值 | 性质 |
|---|---:|---|
| 长度、宽度 | 300、150mm | 规则明确数值 |
| 起拱 | 15mm | 按单段跨度300×0.05计算 |
| 纵向曲线 | 圆弧，半径757.5mm | 试验假设，规则未明确圆弧/抛物线及弧线对应位置 |
| 板厚 | 竖直厚度10mm | 试验假设，不是规则尺寸，不是等法向厚度 |
| 下弧拱顶位置 | Y=130mm | 暂把净高解释为下弧中央净高，仅作坐标参考 |
| 下弧端部/上弧端部/上弧顶部 | 115/125/140mm | 上述假设的计算结果，不代表正式桥面标高 |

规则另有“占据1×2单位区块”与单段300mm的表述，以及连接300mm高台的描述，现有示意图不足以唯一确定桥梁截面、整桥弧线及端部标高。尤其不能把本版上表面140mm当作官方桥面高度，也不能以本版推定下层车过桥净空。应取得官方场地CAD或尺寸答疑后再修订。

## 最小试验

1. 固定两端、低位测试，轮外侧悬空处不能被桌面托住；确认桥板不明显变形。外部支撑不包含在CAD内。
2. 居中缓慢前进、后退，再左右各偏移5mm重复，记录掉边、打滑或需要频繁纠偏。将来仍需整条桥和入口过渡测试。
3. 以轮胎内侧净距g作简化计算，居中时每侧名义搭接为(150−g)/2；偏移d时较差一侧变为(150−g)/2−|d|。例如g=130mm，居中每侧10mm，偏移5mm只剩5mm。此数值不是麦轮滚子的有效接触宽度或稳定保证。

优先使用STEP在切片软件中细化曲面。若打印机放不下300mm，需后续分段并设计不影响行驶的接缝；不要把模型缩小。打印表面与正式场地材料摩擦不同，成功只能作为保留底盘的初步证据。

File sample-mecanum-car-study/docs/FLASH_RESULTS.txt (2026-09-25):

      -------------------------------------------------------------------
                       STM32CubeProgrammer v2.23.0                  
      -------------------------------------------------------------------
ST-LINK SN  : 37FF71064E57343655231443
ST-LINK FW  : V2J37S7
Board       : --
Voltage     : 3.26V
SWD freq    : 950 KHz
Connect mode: Normal
Reset mode  : Software reset
Device ID   : 0x410
Revision ID : Rev A
Device name : STM32F101/F102/F103 Medium-density
NVM size    : 128 KBytes
Device type : MCU
Device CPU  : Cortex-M3
BL Version  : --
Opening and parsing file: crtc-motor.hex
Memory Programming ...
  File          : crtc-motor.hex
  Size          : 5.18 KB 
  Address       : 0x08000000
Erasing memory corresponding to segment 0:
Erasing internal memory sectors [0 5]
Download in Progress:
File download complete
Time elapsed during download operation: 00:00:00.577
Verifying...
File size < 32KB legacy verify will be used
Read progress:
Time elapsed during verifying operation: 00:00:00.084
Download verified successfully
MCU Reset
Software reset is performed
Post-reset readback and register snapshot:
      -------------------------------------------------------------------
                       STM32CubeProgrammer v2.23.0                  
      -------------------------------------------------------------------
ST-LINK SN  : 37FF71064E57343655231443
ST-LINK FW  : V2J37S7
Board       : --
Voltage     : 3.26V
SWD freq    : 950 KHz
Connect mode: Hot Plug
Reset mode  : Software reset
Device ID   : 0x410
Revision ID : Rev A
Device name : STM32F101/F102/F103 Medium-density
NVM size    : 128 KBytes
Device type : MCU
Device CPU  : Cortex-M3
BL Version  : --
UPLOADING ...
  File          : C:\Users\15300\Documents\codex_repos\CRTC\sample-mecanum-car-study\build\readback.bin
  Size          : 5304 Bytes
  Address:      : 0x8000000
Read progress:
Data read successfully
Time elapsed during read operation is: 00:00:00.083
Reading 32-bit memory content
  Size          : 80 Bytes
  Address:      : 0x40000000
0x40000000 : 00000001 00000000 00000000 00000000
0x40000010 : 0000001F 00000000 00006060 00006060
0x40000020 : 00001111 00000163 00000000 00000E0F
0x40000030 : 00000000 00000000 00000000 00000000
0x40000040 : 00000000 00000000 00000000 00000001
Reading 32-bit memory content
  Size          : 80 Bytes
  Address:      : 0x40000400
0x40000400 : 00000001 00000000 00000000 00000000
0x40000410 : 0000001F 00000000 00006060 00006060
0x40000420 : 00001111 00000B69 00000000 00000E0F
0x40000430 : 00000000 00000000 00000000 00000000
0x40000440 : 00000000 00000000 00000000 00000001
Reading 32-bit memory content
  Size          : 8 Bytes
  Address:      : 0x40021000
0x40021000 : 03038583 001D040A
0x2000001C : 00 00 00 00 80 80 80 80
SHA256 BIN/readback: e928fc2b7365dc7399ad571d49d25cd3fda280aa089eed3d909cf4a4609f1355

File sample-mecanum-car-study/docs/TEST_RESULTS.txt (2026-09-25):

2026-09-24 Windows host verification; SANITIZE=0 (MinGW UBSan library unavailable).
PASS: all 6 application C files, real STM32 headers, warnings as errors
PASS: Keil source/include paths exist
PASS: four DRV8833 pairs, signed PWM, saturation, NaN/Inf, reversal write order
PASS: axes, all 256 center checks, deadzone edges, 2197 mixed inputs, ratios
PASS: LSB-first wire simulation, 256 byte values, frame layout, invalid clearing
PASS: startup, invalid-frame stop, neutral rearm, 16 buttons, no phantom release
All host tests passed (not a hardware or Keil build test).

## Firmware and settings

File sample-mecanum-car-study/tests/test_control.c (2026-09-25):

#include <assert.h>
#include <math.h>
#include <stdio.h>
#include <stdlib.h>
#include <string.h>
#include "mock_hardware.h"

/* 将真正的主程序编入测试；不运行无限循环，逐次调用同一 control_step。 */
#define main firmware_main
#include "../hardware/Src/main.c"
#undef main

static void assert_stopped(void)
{
    unsigned i;
    for (i = 0; i < 8; i++) assert(mock_ccr[i] == 0);

}
static void run_frame(uint8_t forward, uint8_t sideways, uint8_t turn,
                      uint16_t pressed, uint8_t mode, uint8_t marker)
{
    uint8_t frame[9] = {0xFF, mode, marker, (uint8_t)~pressed,
                       (uint8_t)~(pressed >> 8), turn, 128, sideways, forward};
    mock_frame(frame, 9);
    control_step();
    mock_assert_poll_complete();
}
static void normal(uint8_t forward, uint8_t sideways, uint8_t turn, uint16_t pressed)
{ run_frame(forward, sideways, turn, pressed, 0x73, 0x5A); }

static void test_pwm(void)
{
    unsigned ch, i, other;
    void (*setters[4])(float) = {pwm_set1,pwm_set2,pwm_set3,pwm_set4};
    const float input[] = {0.0f, 0.00001f, 0.5f, 1.0f, 1.4f,
                           -0.5f, -1.0f, -1.4f, NAN, INFINITY, -INFINITY, -0.0f};
    const int expected[] = {0, 0, 1800, 3600, 3600, -1800, -3600, -3600,
                            0, 3600, -3600, 0};
    for (ch = 0; ch < 4; ch++)
    {
        for (i = 0; i < sizeof input / sizeof input[0]; i++)
        {
            setters[ch](input[i]);
            assert((int)mock_ccr[ch*2] - mock_ccr[ch*2+1] == expected[i]);
            for (other = 0; other < 8; other++)
                if (other / 2 != ch) assert(mock_ccr[other] == 0);
        }
        setters[ch](1.0f); setters[ch](-1.0f); setters[ch](1.0f);
        motor_stop(); assert_stopped();
    }
    puts("PASS: four DRV8833 pairs, signed PWM, saturation, NaN/Inf, reversal write order");
}

static void assert_wheels(int a, int b, int c, int d)
{
    const int expected[4] = {a,b,c,d};
    unsigned i;
    for (i = 0; i < 4; i++)
        assert(abs((int)mock_ccr[2*i] - mock_ccr[2*i+1] - expected[i]) <= 1);
}

static void test_motor(void)
{
    unsigned i, j, k, axis;
    const uint8_t values[] = {0,1,64,119,120,127,128,129,136,137,192,254,255};
    motor(0,128,128); assert_wheels(1800,1800,1800,1800);
    motor(255,128,128); assert_wheels(-1800,-1800,-1800,-1800);
    motor(128,0,128); assert_wheels(1800,-1800,-1800,1800);
    motor(128,128,0); assert_wheels(-1440,-1440,1440,1440);
    /* 未限幅时是 0.6,-0.4,0.4,1.4；应整体除以 1.4，不能逐轮截断。 */
    motor(0,0,0); assert_wheels(1542,-1028,1028,3600);

    for (i = 0; i < 256; i++)
    {
        assert(motor_joystick_is_centered((uint8_t)i) == (i >= 120 && i <= 136));
        motor((float)i, 128, 128);
        if (i >= 120 && i <= 136) assert_stopped();
    }
    motor(119,128,128); assert(mock_ccr[0] > 0);
    motor(137,128,128); assert(mock_ccr[1] > 0);
    motor(NAN,128,128); assert_stopped();
    for (i = 0; i < sizeof values; i++)
        for (j = 0; j < sizeof values; j++)
            for (k = 0; k < sizeof values; k++)
            {
                motor(values[i], values[j], values[k]);
                for (axis = 0; axis < 8; axis++) assert(mock_ccr[axis] <= PWM_PERIOD_COUNTS);
            }
    motor_stop();
    puts("PASS: axes, all 256 center checks, deadzone edges, 2197 mixed inputs, ratios");
}

static void test_ps2(void)
{
    ps2_data data;
    unsigned i;
    uint8_t frame[9] = {0xFF,0x73,0x5A,0xFE,0x7F,3,250,77,199};
    for (i = 0; i < 256; i++)
    {
        frame[5] = (uint8_t)i;
        mock_frame(frame, 9);
        assert(ps2_read(&data) == 1);
        mock_assert_poll_complete();
        assert(data.btn1 == 1 && data.btn2 == 128);
        assert(data.RJoy_LR == i && data.RJoy_UD == 250);
        assert(data.LJoy_LR == 77 && data.LJoy_UD == 199);
    }
    frame[2] = 0;
    mock_frame(frame,9);
    assert(ps2_read(&data) == 0);
    assert(data.mode == 0 && data.btn1 == 0 && data.btn2 == 0);
    assert(data.RJoy_LR == 128 && data.RJoy_UD == 128 &&
           data.LJoy_LR == 128 && data.LJoy_UD == 128);
    memset(frame,0xFF,9); mock_frame(frame,9); assert(ps2_read(&data) == 0);
    memset(frame,0,9); mock_frame(frame,9); assert(ps2_read(&data) == 0);
    assert(ps2_read(NULL) == 0);
    puts("PASS: LSB-first wire simulation, 256 byte values, frame layout, invalid clearing");
}

static void test_control(void)
{
    uint8_t button;
    const uint8_t modes[] = {0,0x41,0x79,0xFF};
    unsigned i;
    control_ready = 0;
    normal(0,128,128,0); assert_stopped(); /* 上电已推杆，不能启动 */
    normal(128,128,128,0); assert_stopped();
    normal(0,128,128,0); assert(mock_ccr[0] > 0);

    for (i = 0; i < sizeof modes; i++)
    {
        run_frame(0,128,128,0,modes[i],0x5A); assert_stopped();
        normal(0,128,128,0); assert_stopped(); /* 连上但未回中 */
        normal(128,128,128,1); assert_stopped(); /* 按键未松 */
        normal(128,128,128,0); assert_stopped();
        normal(0,128,128,0); assert(mock_ccr[0] > 0);
    }
    run_frame(0,128,128,0,0x73,0); assert_stopped();
    normal(128,128,128,0); assert_stopped();

    /* 16 个按键均应在松开时触发一次，按住/持续松开都不重复。 */
    for (button = 0; button < PS2_BUTTON_COUNT; button++)
    {
        last_released_button = 255;
        normal(128,128,128,(uint16_t)(1U << button));
        normal(128,128,128,(uint16_t)(1U << button));
        assert(last_released_button == 255);
        normal(128,128,128,0); assert(last_released_button == button);
        last_released_button = 255;
        normal(128,128,128,0); assert(last_released_button == 255);
    }
    /* 按住时丢帧，不能伪造松开事件；恢复后也不能触发旧动作。 */
    normal(0,128,128,(uint16_t)(1U << PS2_BUTTON_CROSS));
    last_released_button = 255;
    run_frame(0,128,128,0,0xFF,0xFF);
    assert_stopped(); assert(last_released_button == 255);
    normal(128,128,128,0);
    normal(128,128,128,0);
    assert(last_released_button == 255);
    puts("PASS: startup, invalid-frame stop, neutral rearm, 16 buttons, no phantom release");
}

int main(void)
{
    motor_init(); /* 同时初始化两个定时器和八路输出 */
    assert(mock_af_a == (GPIO_Pin_0 | GPIO_Pin_1 | GPIO_Pin_2 | GPIO_Pin_3 |
                         GPIO_Pin_6 | GPIO_Pin_7));
    assert(mock_af_b == (GPIO_Pin_0 | GPIO_Pin_1));
    ps2_init();
    assert(mock_period[0] == 3599 && mock_prescaler[0] == 0);
    assert(mock_period[1] == 3599 && mock_prescaler[1] == 0);
    assert_stopped();
    test_pwm();
    test_motor();
    test_ps2();
    test_control();
    puts("All host tests passed (not a hardware or Keil build test).");
    return 0;
}

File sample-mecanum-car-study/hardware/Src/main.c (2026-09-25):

#include "main.h"

#define CONTROL_LOOP_DELAY_MS  10U
static ps2_data ps2Data;
static uint8_t control_ready = 0;
static uint8_t button_was_down[PS2_BUTTON_COUNT] = {0};

/* Keil Watch 可观察；255 表示尚无松开事件。不会控制任何舵机。 */
volatile uint8_t last_released_button = 255U;

static void buttons_reset(void)
{
    uint8_t button;
    for (button = 0; button < PS2_BUTTON_COUNT; button++)
    {
        button_was_down[button] = 0;
    }
}

/* 用 switch 代替原函数指针数组：以后在相应 case 里写自己的动作。 */
static void on_button_released(uint8_t button)
{
    last_released_button = button;
    switch (button)
    {
        case PS2_BUTTON_CROSS:
            /* TODO_GRIPPER：例如夹爪闭合，目前不驱动舵机。 */
            break;
        case PS2_BUTTON_CIRCLE:
            /* TODO_GRIPPER：例如夹爪打开，目前不驱动舵机。 */
            break;
        default:
            /* 其余按键暂时只记录编号。动作不要长时间阻塞主循环。 */
            break;
    }
}

static void buttons_process(const ps2_data *data)
{
    uint8_t button;
    uint8_t is_down;
    for (button = 0; button < PS2_BUTTON_COUNT; button++)
    {
        /* 先选按键组，再提取对应的那一位。 */
        if (button < 8)
        {
            is_down = (uint8_t)((data->btn1 >> button) & 1U);
        }
        else
        {
            is_down = (uint8_t)((data->btn2 >> (button - 8)) & 1U);
        }
        /* 沿用原项目：从“按下”变成“松开”时，只执行一次。 */
        if (button_was_down[button] && !is_down)
        {
            on_button_released(button);
        }
        button_was_down[button] = is_down;
    }
}

static uint8_t controls_are_neutral(const ps2_data *data)
{
    return motor_joystick_is_centered(data->LJoy_UD) &&
           motor_joystick_is_centered(data->LJoy_LR) &&
           motor_joystick_is_centered(data->RJoy_LR) &&
           data->btn1 == 0 && data->btn2 == 0;
}

/* 单独写成一步，方便逐次调试，也能在电脑上测试异常/恢复的过程。 */
static void control_step(void)
{
    uint8_t frame_valid = ps2_read(&ps2Data);
    if (!frame_valid)
    {
        motor_stop();
        control_ready = 0;
        buttons_reset(); /* 丢包不能被当成“用户松开按钮”。 */
        return;
    }
    if (!control_ready)
    {
        motor_stop();
        buttons_reset();
        /* 上电/异常恢复后，先松开按键并让三个控制轴回中。 */
        if (controls_are_neutral(&ps2Data))
        {
            control_ready = 1;
        }
        return;
    }
    buttons_process(&ps2Data);
    /* uint8_t 会自动转换为函数需要的 float；这里不做速度换算。 */
    motor(ps2Data.LJoy_UD, ps2Data.LJoy_LR, ps2Data.RJoy_LR);
}

int main(void)
{
    delay_init();
    motor_init(); /* 初始化 TIM2/TIM3，八个输入从低电平启动 */
    motor_stop();
    ps2_init();
    while (1)
    {
        control_step();
        /* 通信和计算也耗时，循环总周期不是精确的 10 ms。 */
        delay_ms(CONTROL_LOOP_DELAY_MS);
    }
}

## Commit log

2026-09-22 Add robot CAD models, servo photo fitting and project delivery index
    [01_base.SLDPRT, 01_base.STEP, 02_bearing_tower.SLDPRT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]
2026-10-16 Publish lower-car board link and competition development documentation
2026-10-16 docs: add lower-car BLE WASD dashboard and lower-motor bench issue report
    桌面键盘遥控台（与既有 Android 面板共用同一份 protocol.js 的线协议与安全状态机）：
    - firmware/web/dashboard.html + dashboard.css + dashboard.js + dashboard-input.js
    - WASD 行驶、方向键等效、空格/Esc 急停；未解锁不发车、解锁上升沿清空按键、
    输入框内打字不驱动、失焦/隐藏/断连/调度卡顿一律停止锁定
    - firmware/tests/test_web_dashboard.mjs（18 组）与 test_dashboard_page.py
    （Playwright 真实 Edge + 假 BLE 外设 + 真键盘事件，49 项断言）
    lower-motor 台架首测问题报告（该目标此前从未实板验收）：
    -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
